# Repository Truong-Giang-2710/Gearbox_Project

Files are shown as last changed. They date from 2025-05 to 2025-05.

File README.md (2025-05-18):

📘 Mechanical Transmission System Design – Gearbox Project

🧑‍💻 Introduction
This is a personal project I undertook to strengthen my understanding and skills in the subject of Machine Elements / Mechanical Power Transmission System Design. The project focuses on the design and calculation of a complete mechanical transmission system including gears, shafts, bearings, keys, and the gearbox housing — commonly used in industrial machinery.
All calculations were performed manually, following mechanical engineering standards, design formulas, and technical tables learned throughout the course.

📚 Contents of the Work

I. Power Calculation & Transmission Characteristics
   Analyze working conditions and technical requirements
   Calculate power, torque, and load characteristics
   
II. Motor Selection & Transmission Ratio Distribution
   Select a suitable motor
   Determine the total transmission ratio and allocate it across the stages
   
III. Gear Train Design
   Select gear type: helical cylindrical gears
   Calculate key gear parameters: module, number of teeth, pitch, etc.
   Strength verification: contact stress and bending stress
   
IV. Shaft Design
   Define shaft layout and dimensions
   Calculate bending and torsional moments
   Stress analysis and deformation checks
   Key and spline design
   
V. Bearing Selection
   Choose bearing types based on load and speed
   Calculate bearing life and verify loading capacity
   
VI. Gearbox Housing Design
   Analyze the structure and function of the housing
   Design inspection holes, oil filling/draining holes
   Select bolts, locking rings, sealing elements, and auxiliary parts

🛠️ Tools & Methodologies Used
   Manual calculations based on Vietnamese/ISO mechanical standards
   Data from textbooks 
   Drafting in AutoCAD (optional)

🎯 Project Goals
   Mechanical design and calculation skills
   Develop a deep understanding of how individual machine elements work together in a transmission system
   Serve as a foundation for larger design projects or practical manufacturing applications

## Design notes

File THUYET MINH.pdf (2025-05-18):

### TRƯỜNG ĐẠI HỌC SƯ PHẠM KĨ THUẬT TPHCM

KHOA CƠ KHÍ CHẾ TẠO MÁY

BỘ MÔN CƠ SỞ THIẾT KẾ MÁY

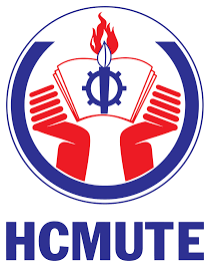
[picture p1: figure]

ĐỒ ÁN TRUYỀN ĐỘNG CƠ KHÍ (MMH: PRMD310523)

THUYẾT MINH TÍNH TOÁN THIẾT KẾ

GVHD : Nguyễn Lê Đăng Hải

GVPB : Nguyễn Văn Đoàn

SVTH : Tống Bạch Trường Giang

MSSV : 21146220
NHÓM: 02

TPHCM , Tháng 12 Năm 2023

Trường ĐHSPKT TP.HCM Khoa: Cơ khí Chế tạo máy Bộ môn: Cơ sở Thiết kế máy | ĐỒ ÁN THIẾT KẾ MÁY, MMH: : PRMD310523 THIẾT KẾ HỆ THỐNG XÍCH TẢI Đề số: 05 -- Phương án: 03
SVTH: Tống Bạch Trường Giang GVHD: Nguyễn Lê Đăng Hải Ngày nhận đề: 28/08/2023 | MSSV: 21146220 Chữ ký: Ngày bảo vệ: 05/01/2024

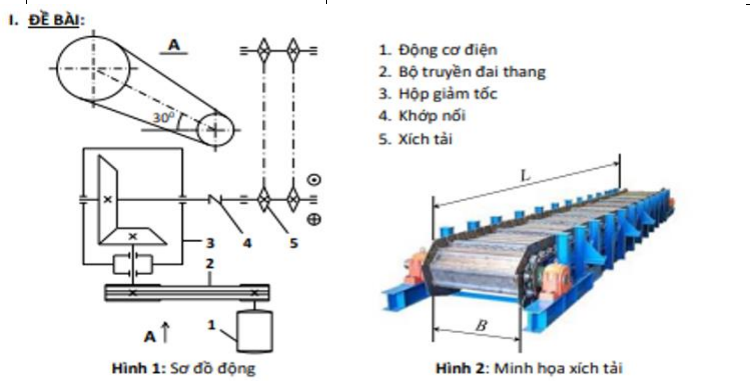
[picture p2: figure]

Điều kiện làm việc:
- Tải trọng không đổi, quay một chiều
- Thời gian làm việc 5 năm (300 ngày/năm, 2 ca/ngày, 6 giờ/ca) - Sai số tỉ
số truyền hệ thống |Δu⁄u| ≤ 5% Số liệu cho trước:
STT | Tên gọi | Giá trị
1 | Bước xích tải p (mm) | 100
2 | Số răng đĩa xích dẫn Z (răng) | 9
3 | Chiều rộng xích tải B (m) | 0,8
4 | Chiều dài xích tải L (m) | 12
5 | Trọng lượng vật đúc G (kG) | 120
6 | Vận tốc xích tải V (m/s) | 0.75
7 | Trọng lượng 1m dài xích tải q (kG/m) | 160

### MỤC LỤC

I. Tính toán công suất , tốc độ trục công tác

### 1.1 Tính toán công suất và tốc độ quay

Tốc độ quay trục công tác:

nlv =

6.10⁴
.V
Z.p

=

6.10⁴
.0,75
9.100

= 50 (v/p)

- Công suất trên trục công tác
Plv = 0,024.q.V.L + 0.00033.Q.L+0.006.Q.B = 3,58 (kW)

Thông số đầu ra :

- Công suất làm việc trên trục công tác : Plv = 3,58 (kW)
- Số vòng quay trên trục công tác : nlv = 50 (v/p)

II. Chọn động cơ và phân phối tỉ số truyền

### 2.1 Thông số đầu vào :

- Công suất cần thiết cần cung cấp: Plv = 3,58 kW
- Số vòng quay trục công tác : nlv = 50 (v/p)

### 2.2 Chọn động cơ :

- Công suất cần thiết trục động cơ : Pctdc=

Plv
η

=

3,58
0,9

= 3.96 kW

- Trong đó :
η = nx × nbrc × nkn × nol

3 = 1× 0,97 × 0.96 × 0,99³ = 0,9 nđ = 0,96 : Hiệu suất bộ truyền đai thang nbrc = 0,97 : Hiệu suất bộ truyền bánh răng côn . nkn = 1 : Hiệu suất khớp nối
nol = 0,99 : Hiệu suất một cặp ổ lăn
η : Hiệu suất truyền toàn hệ thống

+ Chọn sơ bộ tỉ số truyền => Chọn usb = 12

=> Số vòng quay sơ bộ : nsb = usb × nlv = 600 (v/p)
- Chọn động cơ : M2QA160M8A
- Tra bảng ABB với 380V/50Hz và điều kiện : {

Pct ≤ Pđc
nsb ~ nđc

Tmm
T

≤ Kqt ≤

Tk

Tdn

### 2.3 Phân phối tỉ số truyền :

- Tỉ số truyền thực của hệ thống : ut =

nđc

nlv

=

715
50

= 14,3

- Tỉ số truyền truyền động đai : uđ =

ut

ubrc

=

14,3
3,15

= 4,54

- Sai số tỉ số truyền hệ thống : ∆usb =

nđc – nsb

nsb

× 100% = 0.19%

- Sai lệch tỉ số truyền hệ thống :

n3 =

nđc
ut

=

715
14,3

= 50 (

v
p

)

∆uht =

n3 – nlv

nlv

=

50−50
50

∗ 100% = 0%

### 2.4 Bảng thông số kĩ thuật

- Công suất cần thiết trục công tác : Pct =

Plv

nol

=

3,82
0,99

= 3,62 (kW)

- Công suất cần thiết trên trục II : P2 =

Pct

nkn× nol

=

3,62
1×0,99

= 3,65 (kW)

- Công suất cần thiết trên trục I : P1 =

P2

nol × nbrc

=

3,65
0,99×0,97

= 3,96 (kW)

- Công suất cần thiết trục động cơ : Pđc =

P1
nđ

=

3,81
0,96

= 6,57 (kW)

- Số vòng quay trục I : n1 =

nđc
uđ

=

715
4,54

= 157,5 (

vòng
phút)
- Số vòng quay trục II : n2 =

n1
3,15

=

157,5
3,15

= 50 (

vòng
phút)
- Số vòng quay trục công tác : nct =

n2
1

=

50
1

= 50 (

vòng
phút)
- Momen xoắn trục động cơ : Tm =

9,55 ×10⁶×3,96

715

= 52953 N. mm

- Momen xoắn trục I | : T1 =

9,55 ×10⁶×3,81

157,5

= 230774 N. mm

- Momen xoắn trục II | : T2 =

9,55 ×10⁶×3,65

50

= 698081 N. mm

- Momen xoắn trục công tác : Tct =

9,55 ×10⁶×3,62

50

= 691100 N. mm

Động cơ | M2QA_160M8A
Công suất (kW) | 4
Số vòng quay (v/p) | 715
Hệ số quá tải ( Tk ) Tdn | 2,1
Khối lượng (kg) | 120
Đường kính trục động cơ | 42

Trục Thông số | Động cơ | Trục I | Trục II | Trục công tác (trục làm việc)
Công suất P, kW | 3,96 | 3,81 | 3,65 | 3,62
Tỉ số truyền u | 4,54 | 3,15 | 1
Số vòng quay n, vg/ph | 715 | 157,5 | 50 | 50
Mômen xoắn T, N,mm | 52953 | 230774 | 698081 | 691100

III. Tính toán bộ truyền đai

### 3.1 Thông số đầu vào :

- Công suất trên trục dẫn : Pct = 3,96 kW
- Số vòng quay trên trục dẫn: ndc = 715 (

vòng
phút)
- Tỉ số truyền bộ truyền đai: uđ = 4,54
- Đường kính bánh đai nhỏ: d1 =160 (mm)
- Đường kính bánh đai lớn: d2 =710 (mm)
- Tỉ số truyền thực tế : utt =

d2
d1.(1−ε)

=

710
160.(1−0.02)

= 4.53

- Kiểm tra sai lệch tỉ số truyền : ∆u =

ut – u
u

× 100% =

|4,53−4,54|
4,54

× 100% = 0.26% < 4%
- Xác định khoảng cách trục và chiều dài đai:

asơ bộ =

a
d

. d = 0,92.710 = 655,34

- Chiều dài đai tính toán :

l = 2a + π(d1+d2)
2

+

(d2−d1)^2
4a

= 2792,67 (mm)

=> Chọn chiều đai theo tiêu chuẩn : l = 2800 (mm)

- Tính lại chính xác khoảng cách trục :

a = 0,125.(2l-π(d1+d2)+√[2l − π(d1 + d2)] 2 − 8(d2 − d1)^2

= 659,36

- Tính góc ôm và kiểm tra điều kiện góc ôm :

α1 = 180 − 57. (

d2−d1
a

) = 180 -57. (

710−160
659,36

) = 132,45 (độ)

- Xác định số đai Z :

Z = P1⋅kđ
[P0
| ]⋅Cα.Cu.Cl
.Cz

= 2,49 (đai)

=> Chọn z = 3 (đai)

- Chiều rộng bánh đai: B = (z-1)t+2e = (3-1).19+2.12,5 = 63
- Đường kính ngoài của bánh đai : da = d1 + 2h0 = 160 + 2.4,2 = 168,4
- Lực căng ban đầu F0 = 274,23 ( N)
- Lực tác dụng lên trục: = 2F0zsin(α1/2) = 1505,75 (N)

### 3.2 Bảng thông số kĩ thuật bộ truyền đai :

Thông số | Kí hiệu | Gía trị | Đơn vị
Công suất trục dẫn | P | 3,58 | Kw
Tốc độ quay trục dẫn | n | 715 | v/p
Tỉ số truyền thực tế | ut | 4,53
Loại đai | Đai hình thang thường
Đường kính bánh đai nhỏ | d1 | 160 | mm
Đường kính bánh đai lớn | d2 | 710 | mm
Chiều dài đai | l | 2800 | mm
Khoảng cách trục | a | 659,36 | mm
Góc ôm | α1 | 132,45 | độ
Lực căng ban đầu | F0 | 274,23 | mm
Lực tác dụng lên trục | Fr | 1505,75 | N
Số đai | z | 4 | đai

IV. Tính toán thiết kế bộ truyền bánh răng

### 4.1 Thông số đầu vào :

- Công suất trên trục I : P1 = 3,81 N
- Tốc độ quay trên trục I : n1 = 157,5 (

v
p

)

- Tỉ số truyền bánh răng côn : ubrc = 3,15
- Thời gian làm việc : LH = 18000 (giờ)
- Momen xoắn trên trục I : T1 = 230774 N.mm

### 4.2 Tính toán bộ truyền bánh răng côn 4.2.1 Bảng thông tin vật liệu chế tạo bánh răng :

| Vật liệu | Nhiệt luyện | Độ cứng HB | Giới hạn bền σb (MPa) | Giới hạn cứng σch (MPa) | [σH] MPa | [σH]max MPa | [σF]max MPa
Bánh răng dẫn | C45 | Tôi cải thiện | 243 | 850 | 580 | 505,45 | 1624 | 464
Bánh răng bị dẫn | C45 | Tôi cải thiện | 228 | 750 | 450 | 478,18 | 1260 | 360

### 4.2.2 Xác định ứng suất cho phép 4.2.2.1 Ứng suất tiếp xúc cho phép :

[σH1] = σHlim1×KHL1
SH

=

570×1
1,1

= 505,45 MPa

[σH2] = σHlim2×KHL2
SH

=

540×1
1,1

= 478,18 MPa

Trong đó:
- σHlim1= 2×HB1 + 70 = 556 MPa : Ứng suất tiếp cho phép
- σHlim2= 2×HB2 + 70 = 526 MPa : Ứng suất tiếp cho phép
- [σH] = min {[σH1] , [σH2]} = 478,18 MPa
- SH = 1,1 : hệ số an toàn khi tính về tiếp xúc
- KFL = 1
- NHO = 30 × HB: Số chu kì thay đổi ứng suất khí tiếp xúc .
- NHE = 60 × c × n × LH = 170100000

- LH = 18000 : thời gian làm việc (giờ)
- Do NHE1,2 > NHO1,2 → NHE1,2 = NHO1,2
4.2.2.2 Ứng suất uốn cho phép :

[σF1] = σFlim1×KFC×KFL

| SF = 450×1×1
| 1,75 = 257,1 MPa

[σF2] = σFlim2×KFC×KFL

| SF = 423×1×1
| 1,75 = 241,7 MPa

Trong đó:
- σFlim1= 1,8×HB1 = 437 MPa : Ứng suất uốn cho phép
- σFlim2= 1,8×HB2 = 410 MPa : Ứng suất uốn cho phép
- SF = 1,75 : hệ số an toàn khi tính về uốn
- KFL = (
| NFO NFE
)
| 1 mF = 1 ∶ hệ số tuổi thọ xét đến ảnh hưởng tải trọng
- KFC = 1 : hệ số xét đến ảnh hưởng đặt tải
- NHO = 30 × HB ∶ Số chu kì thay đổi ứng suất khí tiếp xúc .
- NFO = 4 × 10⁶
| ∶ Số chu kì thay đổi ứng suất cơ sở khi uốn
- NHE = 60 × c × n × LH = 170100000
- c = 1 ∶ số lần tiếp xúc / vòng quay
- LH = 18000 : thời gian làm việc (giờ)
- Do NFE1,2 > NFO1,2 → NFE1,2 = NFO1,2
4.2.2.3 Ứng suất tiếp cho phép khi quá tải. [σH1]max = 2,8 × σch1 = 2,8 × 580 = 1624 MPa [σH2]max = 2,8 × σch2 = 2,8 × 450 = 1260 MPa 4.2.2.4 Ứng suất uốn cho phép khi quá tải. [σF1]max = 0,8 × σch1 = 0,8 × 580 = 464 MPa [σH2]max = 0,8 × σch2 = 0,8 × 450 = 360 MPa

### 4.2.3 Xác định sơ bộ chiều dài côn ngoài

Re = KR × √u

2 + 1 × √
(T1×KHβ)
(1−Kbe)×Kbe×u×[σH]

2 = 203,47 (mm)

Trong đó :
- KR = 50 : hệ số phụ thuộc vào vật liệu bánh răng và loại răng
- KHβ = 1,09 : hệ số kể đến ảnh hưởng đến sự phân bố không đều tải trọng trên chiều rộng vành răng
- Kbe =

b
Re

= 0,25 vì u > 3

- Đường kính chia ngoài :
de1 = 2 ×

Re
√1+u² = 2 ×

203,47
√1+3,15²

= 123,13 (mm)

- Xác định số răng bánh dẫn :
z1 = 1,6× z1p = 1,6 × 19,93 = 31,88 → Chọn z1 = 32 (răng)
- Đường kính trung bình : dm1 = (1 − 0,5 × Kbe) × de1 = 107,74 (mm)
- Modun trung bình : mtm =

dm1
z1

=

107,74
32

= 3,37

- Modun vòng ngoài:
mte =

mtm
1−0,5.Kbe

=

3,37
1−0,5.0,25

= 3,85 , chọn mte = 4

Tính lại mtm = mte ×(1 − 0,5 × Kbe) = 3,5
- Tính lại số răng z1 =

dm1

mtm

=

107,74
3,5

= 30,78 −→ chọn z1 = 31 răng

➔ z2 = u× z1 = 3,15× 31 = 97,65 → Chọn z2 = 98 răng
- Tính lại tỉ số truyền thực tế: utt =

z2
z1

=

98
31

= 3,16

- Sai lệch tỉ số truyền :

∆u =

utt – ubrc

ubrc

× 100% =

|3,16−3,15|
3,15

× 100% = 0,36% < 4%

- Sai lệch tỉ số truyền hệ thống:

∆u =

n3– nlv

nlv

× 100% =

|49,94−50|
50

× 100% = 0,1% < 5%

Trong đó:
- n3 =

nđc

ubrtt×ut

=

715
3,16×4,53

= 49,95 (

v
p

)

- Xác định góc ôm chia theo công thức: δ1 = arctg (

z1
z2

) = 17,55°

δ2 = 90° − 17,55° = 72,45°

- Đường kính trung bình và chiều dài côn ngoài: dm1 = z1 × mtm = 31×3,5 = 108,5 mm
Re = 0,5 × mte × √z1
2 + z2

2 = 205,57 mm
- Độ rộng vành răng b = Kbe × Re = 51,39 mm

### 4.2.4 Kiểm nghiệm răng về độ bề tiếp xúc

σH = zM × zH × zξ√
2×T1×KH×√u²+1
0,85×b×u×dm1

2
= 274× 1,76 × 0,87 × √
2×87753×1,24×√3,17²+1
0,85×36,17×3,17×76,125²

= 474 ,82 MPa ≤ [σH]

Trong đó:
- zM = 274 : hệ số kể đến cơ tính vật liệu của các bánh răng khớp
- zH = 1,76 : hệ số kể đến hình mặt bề mặt tiếp xúc
- zξ = √
4−ξα
3

= √
4−1,73
3

= 0,87 hệ số kể đến sự trùng khớp của răng

- ξα = [1,88 − 3,2 × (

1
z1

+

1
z2

)] × cos (0) = 1,73

- KH = kHβ × kH∝ × kHv = 1,15: hệ số tải trọng khi tính về tiếp xúc
- kHβ = 1,09
- kH∝ = 1 : hệ số kể đến sự phân bố không đều tải trọng cho các đôi răng khi đồng thời ăn khớp.
- kHv = 1 +

vH×b×dm1
2×T1×kHβ×kH∝

= 1,05 : hệ số kể đến tải trọng xuất hiện trong vùng

ăn khớp
- vH = δH × go × v × √
dm1×(u+1)
u
= 0,006× 56 × 0,89 × √
108,5×(3,15+1)
3,15

= 4,69 ≤ VHmax = 700

- δH = 0,006 : ảnh hưởng sai số ăn khớp
- go = 73: ảnh hưởng sai lệch các bước bánh răng 1 và 2
- v = dm1 × π ×

n
60000

= 0.89

- VHmax = 380 : khả năng chịu tải trọng lớn của bánh răng
- Kiểm nghiệm độ bền: σH ≤ [σH]
[σH] − σH
[σH]

× 100% =

434,99 − 478,18
478,18 × 100% = 9% < 10%

### 4.2.5 Kiểm nghiệm răng về độ bền uốn

σF1 =

2×T1×KF×Yξ×Yβ×YF1
0,85×b×mtm×dm1

=

2×230774×1,33×0,57×1×3,79
0,85×51,39×3,5×108,5

= 80,17 MPa

σF2 =

σF1×YF2

YF1

=

80,17×3,6
3,79

= 76,17 MPa

Trong đó:
- Yξ =

1
ξα

= 0,57 : hệ số kể đến sự trùng khớp của răng

- Yβ = 1 −

β

°

140

= 1 : hệ số kể đến độ nghiên của răng

- {

YF1 = 3,82
YF2 = 3,6

: hệ số dạng răng của bánh răng 1 và 2

- zv1 =

z1
[cos (β°)]

3 = 31

- zv2 =

z2
[cos (β°)]

3 = 98

- KF = kFβ × kF∝ × kFv = 1,33 : hệ số tải trọng khi tính về uốn
- kFβ = 1,175 tra bảng 6,21 : hệ số kể đến sự phân bố không đều tải trọng trên chiều rộng vành răng.
- kF∝ = 1 : hệ số kể đến sự phân bố không đều tải trọng cho các đôi răng khi đồng thời ăn khớp.
- kFv = 1 +

vF×b×dm1
2×T1×kFβ×kF∝

= 1 +

12,49×51,39×108,5
2×230774×1,175×1

= 1,13 : hệ số kể đến tải trọng

xuất hiện trong vùng ăn khớp
- vF = δF × go × v × √
dm1×(u+1)
u
= 0,016× 73 × 0,89 × √
108,5×(3,15+1)
3,15

= 12,49

- δF = 0,016 : ảnh hưởng sai số ăn khớp
- go = 73: ảnh hưởng sai lệch các bước bánh răng 1 và 2

### 4.2.6 Kiểm nghiệm răng về quá tải

- Kiểm tra ứng suất tiếp cực đại cho phép
σHmax = σH × √Kqt = 434,99× √1 = 434,99 ≤ [σHmax] -Kiểm nghiệm ứng suất uốn cực đại cho phép:
σF1max = σF1 × Kqt = 80,17 × 1 = 80,17≤ [σF1max] σF2max = σF2 × Kqt = 76,17 × 1 = 76,17≤ [σF2max]

### 4.2.7 Lực tác dụng khi ăn khớp:

- Lực vòng : Ft1 = 2 ×

T1

dm1

= 2 ×

230774
108,5

= 4253,91 = Ft2

- Lực hướng tâm :
Fr1 = Ft1 × tg(∝) × cosδ1 = Fa2
= 4253,91 × tg(20°) × cos(17,55°) = 1476,2 N
- Lực dọc trục ∶
Fa1 = Ft1 × tg(∝) × sinδ1 = Fr2
= 4253,91 × tg(20°) × sin(17,55°) = 466,96 N

### 4.2.8 Các thông số khác :

- Đường kính chia ngoài:
{

de1 = mte × z1 = 4 × 31 = 124 mm de2 = mte × z2 = 4 × 98 = 392 mm
- Chiều cao đầu răng ngoài :
{

hae1 = hte + x × cos (0) = 5,212 mm hae2 = 2 × hte × mte − hae1 = 2,788 mm
- Chiều cao răng ngoài
he = 2 × hte × mte + c = 8,8 mm , hte = 1
- Chiều cao chân răng ngoài :
{

hfe1 = (he − hae1) = 3,588 mm
hfe2 = (he − hae2) = 6,012 mm
- Đường kính đỉnh côn ngoài: {

da1 = de1 + 2 × hae1 × cos (δ1) = 133,94 mm da2 = de2 + 2 × hae2 × cos (δ2) = 393,68 mm

### 4.3 Bảng thông số kĩ thuật bộ truyền bánh răng côn:

Thông số | Ký hiệu | Giá trị | Đơn vị
Tỉ số truyền | ubr | 3.15
Chiều dài côn ngoài | Re | 205,57 | mm
Mô đun vòng ngoài | mte | 4 | mm
Số răng của bánh răng dẫn | z1 | 31 | răng
Số răng của bánh răng bị dẫn | z2 | 98 | răng
Đường kính chia ngoài của bánh dẫn | de1 | 124 | mm
Đường kính chia ngoài của bánh bị dẫn | de2 | 392 | mm
Góc côn chia của bánh dẫn | δ1 | 17.55 | độ
Góc côn chia của bánh bị dẫn | δ2 | 72.45 | độ
Đường kính đỉnh răng ngoài của bánh dẫn | dae1 | 133.94 | mm
Đường kính đỉnh răng ngoài của bánh bị dẫn | dae2 | 393.68 | mm
Đường kính trung bình của bánh dẫn | dm1 | 108.5 | mm
Đường kính trung bình của bánh bị dẫn | dm2 | 343 | mm
Chiều cao răng ngoài | he | 8.8 | mm
Chiều cao đầu răng ngoài của bánh dẫn | hae1 | 5.212 | mm
Chiều cao đầu răng ngoài của bánh bị dẫn | hae2 | 2.788 | mm
Chiều cao chân răng ngoài của bánh dẫn | hfe1 | 3,588 | mm
Chiều cao chân răng ngoài của bánh bị dẫn | hfe2 | 6.012 | mm
Lực vòng | Ft1 = Ft2 | 4253 | N

Lực hướng tâm | Fr1, Fr2 | 1476;466 | N
Lực dọc trục | Fa1, Fa2 | 466;1476 | N
V. Tính toán thiết kế trục

### 5.1 Thông số đầu vào :

- Momen xoắn cần truyền: T = 698081 (N.mm)
- Đặc trưng tải trọng : máy công tác thùng trộn

### 5.2 Chọn nối trục :

- Momen xoắn tính toán: Tt = k× T = 1,5 × 698081 = 1047121 N.mm Trong đó k = 1,5 : hệ số an toàn làm việc
- Chọn đường kính sơ bộ tại vị trí lắp trục
d ≥ √
1047121
0,2×22

3
= 61,97 (mm)

➔ Chọn d = 63 mm
- Kích thước cơ bản của nối trục vòng đàn hồi.
T (N.m) | d | D | dm | L | l | d1 | D0 | Z | nmax | B | B1
2000 | 63 | 260 | 120 | 175 | 140 | 110 | 200 | 8 | 2300 | 8 | 70
T (N.m) | l1 | D3 | l2 | dc | d1 | D2 | l | l1 | l2 | l3 | h
2000 | 48 | 48 | 48 | 24 | M16 | 32 | 95 | 52 | 24 | 44 | 2

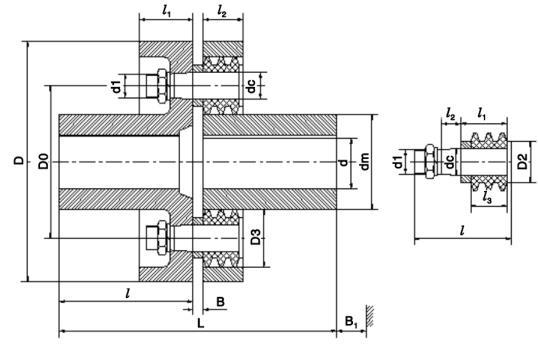
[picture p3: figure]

- Điều kiện sức bền dập vòng đàn hồi:

σd =

2×k×T
Z×D0×dc×l3

=

2×1,5×698081
8×200×24×44

= 1,24 MPa ≤ (2 ÷ 4)MPa

- Điều kiện bền của chốt :

σu =

k×T×l0
0,1×D0×dc

3×Z

=

1,5×698081×72
0,1×200×24³×8

= 34,09 MPa ≤ [σu]

l0 = l1 +

l2
2

= 48 +

48
2

= 72 (mm)

- Lực nối trục : Frnt = 0,2 × 2 ×

698081
200

= 1745,2 N.

### 5.3 Tính toán thiết kế trục :

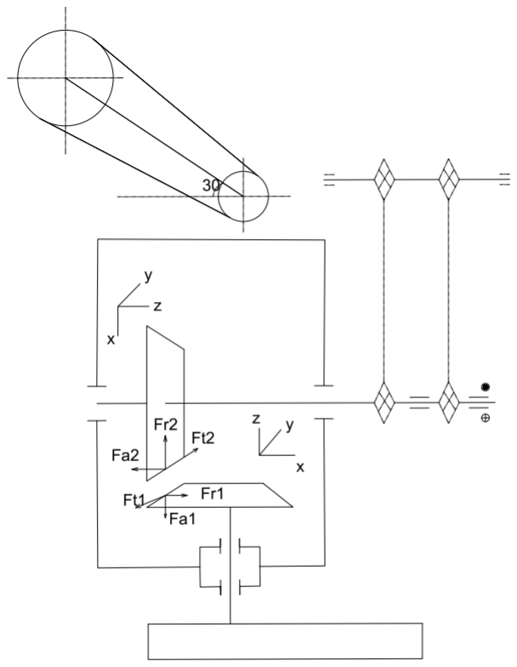
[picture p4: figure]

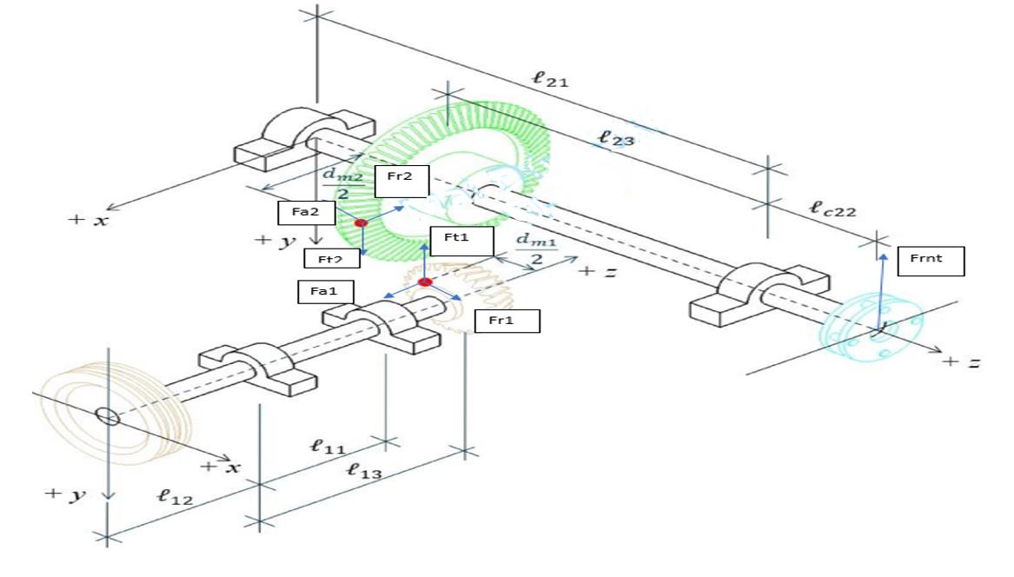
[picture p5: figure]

### 5.3.1 Tính toán tải tác dụng lên trục:

- Lực vòng : Ft1 = Ft2 = 2 ×

T1

dm1

= 2 ×

230774
108,5

= 4253,92 N
- Lực hướng tâm : Fr1 = Fa2 = Ft1 × tg(∝) × cosδ1 = 4253,92 × tg(20°) × cos(17,55°) = 1476,2 N
- Lực dọc trục : Fa1 = Fr2 = Ft1 × tg(∝) × sinδ1 = 2305,5 × tg(20°) × sin(17,49°) = 252,2 N

### 5.3.2 Tính toán sơ bộ đường kính trục

d1 ≥ √
T1
0,2×[τ1]

3

= √
230774
0,2×18

3
= 40 mm => Chọn d1 = 45 mm

d2 ≥ √
T2
0,2×[τ2]

3

= √
265488
0,2×22

3
= 54,14 mm => Chọn d2 =55 mm

Trong đó:
- {

[τ1] = 18
[τ2] = 22

∶ Ứng suất trượt cho phép.

### 5.3.3 Khoảng cách giữa các gối đỡ

- Chiều dài mayo mấy răng côn trục I :
lm13 = (1,2 ÷ 1,4) × d1 = 1,3.45 = 58,5 mm
- Chiều dài mayo bánh đai
lm12 = (1,4 ÷ 2,5) × d1 = 1,5.45 = 67,5 mm
- Chiều dài mayo mấy răng côn trục II :
lm23 = (1,2 ÷ 1,4) × d2 = 1,3.55 = 71,5mm
- Chiều dài mayo khớp nối trục II:
lm22 = (1,2 ÷ 1,5) × d2 = 1,5.55 = 82,5mm Chọn sơ bộ bề rộng ổ lăn:
d1 = 35 mm → chọn b01 = 21 mm
d2 = 40 mm → chọn b02 = 23 mm

### 5.3.4 Chọn trị số các khoảng cách

- k1 = 15 : Khoảng cách từ mặt mút chi tiết quay đến thành trong của hộp
- k2 = 10 : Khoảng cách từ mặt mút ổ đến thành trong của hộp
- k3 = 20 : Khoảng cách từ mặt mút của chi tiết quay đến nắp ổ
- hn = 20 : Chiều cao nắp ổ và đầu bu lông .

### 5.3.5 Khoảng cách trục I:

lc12 = 0,5× (lm12 + b01)+k3+hn = 0,5× (67,5 + 25) + 20 + 20 = 86,25 mm l12 = lc12 = 86,25 mm
l11 = (2,5 ÷ 3) × d1= 135 mm
l13 = l11+k1+k2+lm13+0,5×(b01- b13 × cos (δ1)) = 206,5 mm

### 5.3.6 Khoảng cách trục II:

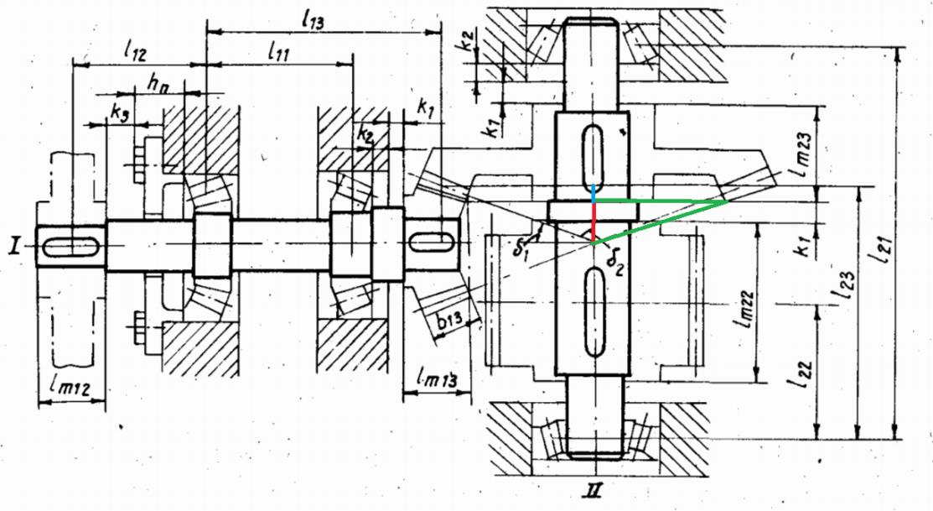
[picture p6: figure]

- Góc tạo bởi đỉnh bánh răng lớn và đường ăn khớp : θ = arctg (

hae2
Re

) = arctg (

2,788
205,57) = 0,78°
- Góc tạo bởi đỉnh bánh răng lớn và tâm trục I:
γ = δ1 − θ = 17,55 – 0,78= 16,77°
- Bề rộng đỉnh bánh răng lớn :
b1 = b × cos(θ) = 51,39 × cos(0,78) = 51,385 mm
- Khoảng cách đoạn màu đỏ :
y = cos(16,77) ×51,385=49,2 mm
- Khoảng cách từ

b
2

đến đường tâm trục I (đỏ + xanh)

s = √(Re −
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
× cos(δ1

))

2
= 54,01 mm
- Khoảng cách trục II :
lc22 = 0,5× (lm22 + b02)+k3+hn = 0,5×(82,5+29)+20+20 = 95,75 mm l21= 2× (

b02
2

+ k1 + k2 + lm23 + y) = 320,4 mm

l23 = (

l21
2

+ s) = 214,44 mm

l22 = lc22 = 95,75 mm

### 5.4 Vẽ biểu đồ momen nội lực :

### 5.4.1 Tính phản lực trên trục I :

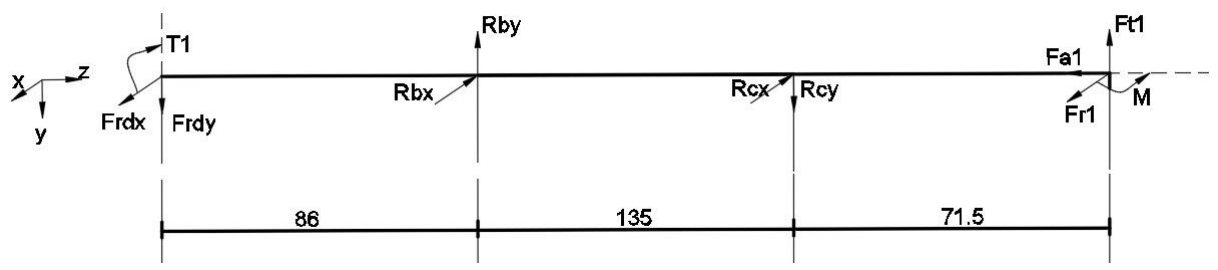
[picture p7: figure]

Xét Oyz :

MB = 0 Frdy.l12+Ft1.l13-Rcy.l11=0

- 752,88.86,25+4253,91.206,5- Rcy.135 = 0
- Rcy = 6987,92 (N)
Fy = 0 | Frdy +Rcy -Ft1 – Rby = 0
| 752,88 + 6987,92-4253,92 – Rby = 0
| Rby = 3486,88 (N)

Xét Oxz : -Frdx.l12+Fr1.l13-M1 – Rcx.l11 = 0

| -1304,02.86,25+1476,2.206,5-25332,69- Rcx .135= 0
| Rcx = 1237,27 (N)
Fx = 0 | Frdx -Rcx +Fr1 – Rbx = 0
| 1304,02 - 1237,27+1476,2 – Rbx = 0
| Rbx = 1542,95 (N)

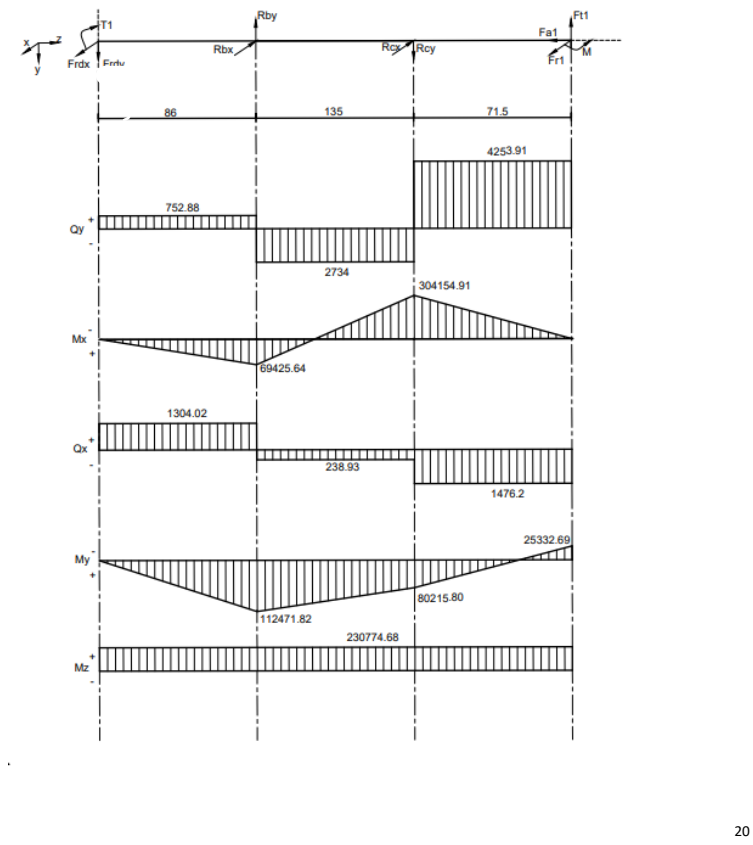
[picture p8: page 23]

### 5.4.2 Phản lực trên trục II :

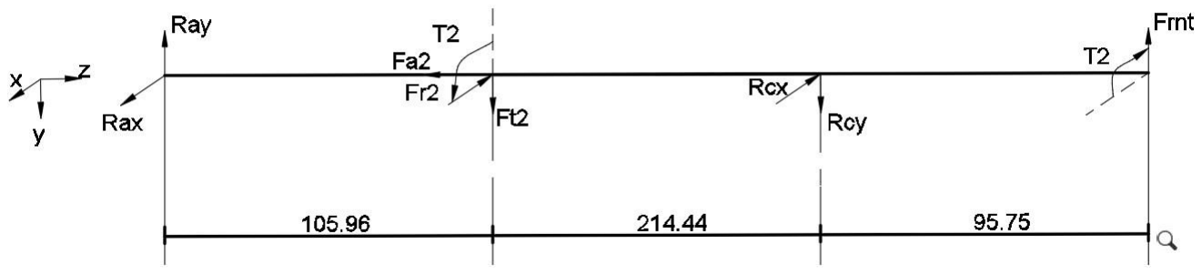
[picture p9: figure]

MC = 0 Ft2.l23+Frnt.l22-Ray.l21=0

- 4253,91.214,44+1745,2.95,75- Ray.320,4 = 0
- Ray = 3368,64 (N)
Fy = 0 | Frnt +Ray -Ft2 – Rcy = 0
| 1745,2 + 3368,64-4253,92 – Rcy = 0
| Rcy = 859,93 (N)

MC = 0 Fr2.l23+ M – Rax.l21 = 0

466,96.214,44 +253168,76- Rax .320,4= 0

- Rax = 1102,7 (N)
Fx = 0 | Rax -Fr2 – Rcx = 0
| 1102,69 -466,96 – Rcx = 0
| Rcx = 635,73 (N)

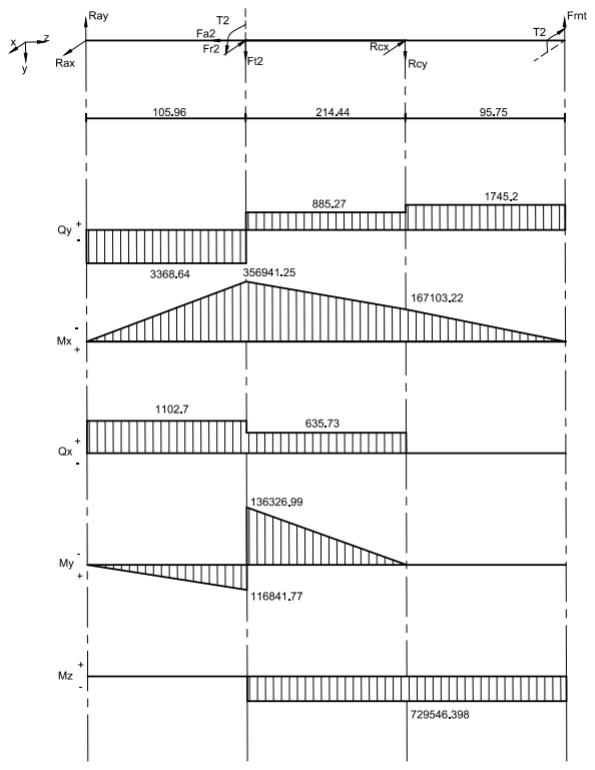
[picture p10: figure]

### 5.5 Tính đư

ờng kính tr
ục t

ại các ti

ết di
ện nguy hi

ểm :

- Trục I : Đư
ờng kính tr

ục đ
ộng cơ D = 42 mm
- Tra b
ảng 10.5 , t

ừ

d
1

= 45 mm
C

h
ọn

σ
1

= 55 MPa
•

T

ại ti

ết di
ện A

d
A

≥

√
MtdA

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
= 33,12 => Ch
ọn

d
A = 34 mm

•

T

ại ti

ết di
ện B

d
B

≥

√
MtdB

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
= 35,12 =>Ch
ọn

d
B = 45 mm

•

T

ại ti

ết di
ện C

d
C

≥

√
MtdC

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
= 40,77 =>Ch
ọn

d
C = 45 mm

•

T

ại ti

ết di
ện D

d
D

≥

√
MtdD

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
= 33,21 => Ch
ọn

d
D = 34 mm
- Trục II : • Tra bảng 10.5 , t ừ

d
1

= 55 mm

, ch
ọn

σ
1

= 55 MPa
•

T

ại ti

ết di
ện A

d
A

≥

√
MtdA

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
= 0 , Ch
ọn

d
A = 65 mm

•

T

ại ti

ết di
ện B

d
B

≥

√
MtdB

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
= 51,2 , Ch
ọn

d
B = 70 mm

•

T

ại ti

ết di
ện C

d
C

≥

√
MtdC

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
= 49,16 , Ch
ọn

d
C = 65 mm

•

T

ại ti

ết di
ện D

d
D

≥

√
MtdD

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
= 48,61 , Ch
ọn

d
D = 63 mm

### 5.6 Chọn và kiểm nghiệm then :

- Dựa vào đường kính trục chọn theo bảng sau:
| d(mm) | Kích thước tiết diện | Chiều sâu rãnh | Vị trí lắp
b | h | t1 | lt
Trục I | A | 34 | 10 | 8 | 5 | 57,38 | Bánh đai
| D | 34 | 10 | 8 | 5 | 49,73 | Bánh răng dẫn
Trục II | B | 70 | 20 | 12 | 7,5 | 60,78 | Bánh răng bị dẫn
| D | 63 | 18 | 11 | 7 | 70,13 | Khớp nối
- Tính chiều dài then:

Trục I: {

Tại A: ltA = (0,8 ÷ 0,9) × lm12 = 57,4 mm Tại D: ltD = (0,8 ÷ 0,9) × lm13 = 49,7 mm Trục II: {

Tại B: ltB = (0,8 ÷ 0,9) × lm23 = 60,8 mm Tại D: ltD = (0,8 ÷ 0,9) × lm22 = 70,1 mm
- Kiểm nghiệm then:
Trục I
Tại tiết diện A : {
σd =

2×T1
dA×ltA×(h−t1)

=

2×230774
34×57,4×(8−5)

= 78,87 ≤ [σd]

τC =

2×T1
dA×ltA×b

=

2×230774
34×57,4×10

= 23,66 ≤ [τc

]

Tại tiết diện D : {
σd =

2×T1
dD×ltD×(h−t1)

=

2×230774
34×49,7×(8−5)

= 91 ≤ [σd]

τC =

2×T1
dD×ltD×b

=

2×230774
34×49,7×10

= 27,3 ≤ [τc

]

Trục II:
Tại tiết diện B : {
σd =

2×T2
dB×ltB×(h−t1)

=

2×729546
70×60,8×(12−7,5)

= 76,22 ≤ [σd]

τC =

2×T2
dB×ltB×b

=

2×729546
70×60,8×20

= 17,15 ≤ [τc

]

Tại tiết diện D : {
σd =

2×T2
dD×ltD×(h−t1)

=

2×729546
63×70,1×(11−7)

= 82,57 ≤ [σd]

τC =

2×T2
dD×ltD×b

=

2×729546
63×70,1×18

= 17,78 ≤ [τc

]

### 5.7 Kiểm nghiệm về bền mỏi Trục :

σ−1 = 0,436 × σb = 0,436 × 850 = 370,6 MPa τ−1 = 0,58 × σ−1= 214,95 MPa
- Bảng 10.7 chọn ψσ = 0,1 , ψτ = 0,05 .
- Bảng 10.12 với σb = 850 → nội suy => {

kσ = 1,6575
kτ = 1,965
- Bảng 10.11 chọn {

kσ
ξσ

= 3,375

kτ
ξτ

= 2,425

- Kiểm nghiệm trục về độ bền mỏi tại các vị trí nguy hiểm
Trục | dA1 | dD1 | dB2 | dD2
d(mm) | 34 | 34 | 70 | 63
εσ | 0,85 | 0,85 | 0,76 | 0,81
ετ | 0,78 | 0,78 | 0,73 | 0,76

VI. Chọn ổ lăn

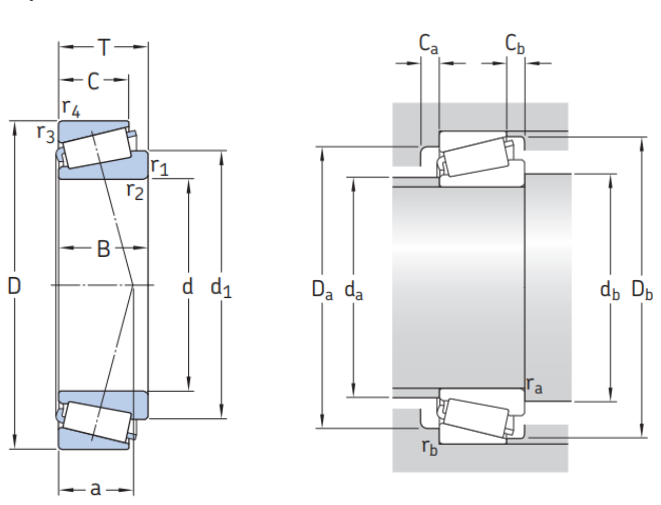
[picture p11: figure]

### 6.1 Trục I :

6.1.1 Thông số đầu vào :
- Đường kính tại B và C: dB = dC = 45 mm
- Momen xoắn trục I : T1= 230774 N.mm
- Tốc độ quay trục : n1= 715 v/p
6.1.2 Chọn loại ổ
- Chọn kích thước ổ:
Kí hiệu | d | D | B | Tải tỉnh Co (KN) | Tải động C (KN) | Khối lượng(Kg) | e
32008X/Q | 45 | 80 | 26 | 43 | 44,6 | 13,67 | 0,37

### 6.2 Trục II:

6.2.1 Thông số đầu vào :
- Đường kính tại B và D : dB = dC = 65 mm
- Momen xoắn trục II : T2= 729546 N.mm
- Tốc độ quay trục : n2= 50 v/p
6.2.2 Chọn loại ổ
- Chọn kích thước ổ:
Kí hiệu | d | D | B | Tải tỉnh Co (KN) | Tải động C (KN) | Khối lượng(Kg) | e
JM511946 | 65 | 110 | 28 | 183 | 123 | 1.05 | 0,88

PHẦN VII: THIẾT KẾ VỎ HỘP

Bảng thông số vỏ hộp:
Vật liệu đúc vỏ hộp: gang xám GX 15-32
Tên gọi | Thông số | Giá trị | Đơn vị
Chiều dày | Thân hộp | δ | 9 | mm
| Nắp hộp | δ1 | 8 | mm
Đường kính | Bulông nền | d1 | 16 | mm
| Bulông cạnh ổ | d2 | 12 | mm
| Bulông ghép bích nắp và thân | d3 | 10 | mm
| Vít ghép nắp ổ | d4 | 8 | mm
| Vít ghép nắp cửa thăm | d5 | 6 | mm
Mặt bích ghép nắp và thân | Chiều dày bích thân hộp | S3 | 16 | mm
| Chiều dày bích nắp hộp | S4 | 16 | mm
| Bề rộng bích nắp và thân | K3 | 37 | mm
Kích thước gối trục | Đường kính ngoài và tâm lỗ vít | D12 | 75 | mm
| | D13 | 90 | mm
| | D22 | 100 | mm
| | D23 | 125 | mm
| Bề rộng mặt ghép bulông cạnh ổ | K2 | 45 | mm
| Tâm lỗ bulông cạnh ổ | C1 | 45 | mm
| | C2 | 63 | mm
| Chiều dày | e | 8 | mm
| Chiều cao | h | < 58 | mm

Gân tăng cứng

Độ dốc | | 2 o
Mặt đế hộp | Chiều dày (không có phần lồi) | S1 | 24 | mm
| Bề rộng mặt đế hộp | K1 | 48 | mm
Khe hở giữa các chi tiết | Giữa bánh răng và thành trong hộp | ∆ | 10 | mm
| Giữa bánh răng lớn với đáy hộp | ∆1 | 24 | mm
| Giữa mặt bên các bánh răng với nhau | ∆ | 10 | mm
Số lượng bulông nền | | Z | 4

Một số chi tiết phụ :
- Bulông vòng:
- Chức năng: để nâng và vận chuyển hộp giảm tốc (khi gia công, khi lắp ghép,…) nên nắp và thân thường lắp bulông vòng hoặc vòng móc.
- Với Re = 144,69 mm
- khối lượng hộp giảm tốc bánh răng côn Q = 60 kg

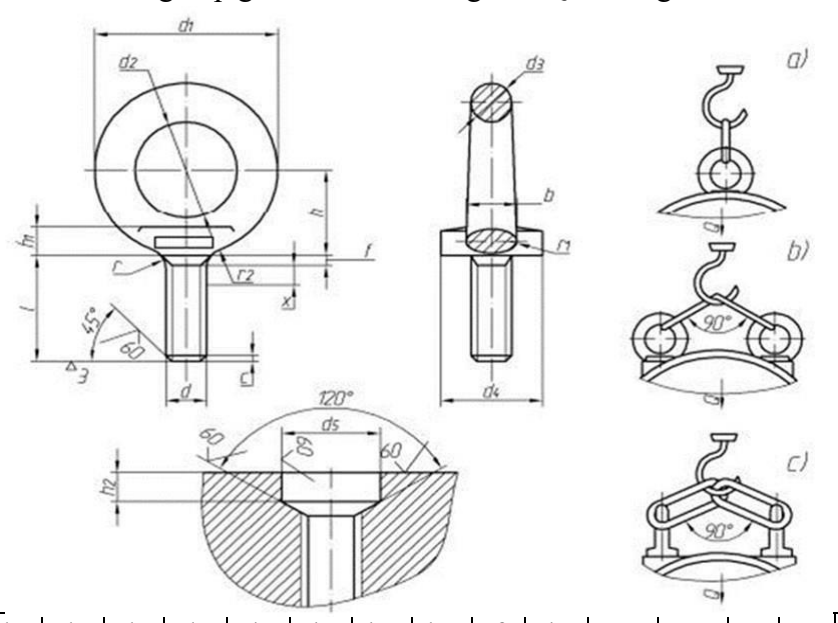
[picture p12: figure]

Ren d | d1 | d2 | d3 | d4 | d5 | h | h1 | h2 | f | b | c | x | r | r1 | r2 | l
M8 | 36 | 20 | 8 | 20 | 13 | 18 | 6 | 5 | 2 | 10 | 1.2 | 2.5 | - | 4 | 4 | 18
- Chốt định vị:
- Chức năng: khi xiết bulông không làm biến dạng vòng ngoài của ổ, do đó loại trừ được một trong nguyên nhân làm ổ chóng bị hỏng. Chọn chốt định vị: chốt định vị hình côn

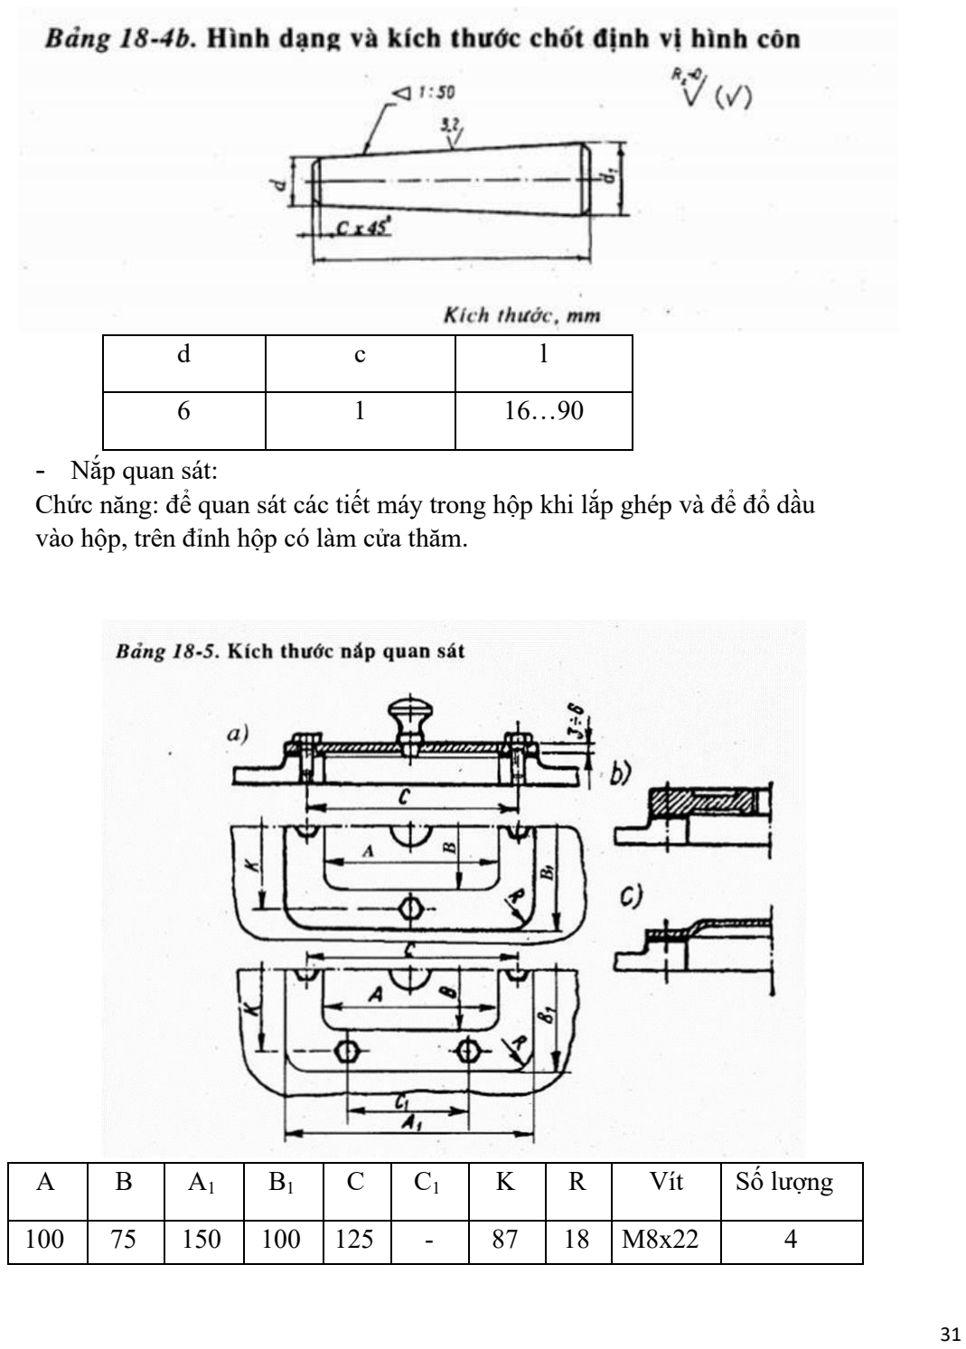
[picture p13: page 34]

d | c | l
6 | 1 | 16…90
- Nắp quan sát:
Chức năng: để quan sát các tiết máy trong hộp khi lắp ghép và để đổ dầu vào hộp, trên đỉnh hộp có làm cửa thăm.
A | B | A1 | B1 | C | C1 | K | R | Vít | Số lượng
100 | 75 | 150 | 100 | 125 | - | 87 | 18 | M8x22 | 4

- Nút thông hơi:
- Chức năng: khi làm việc nhiệt độ trong hộp tăng lên. Để giảm áp suất và điều hòa không khí bên trong và bên ngoài hộp, người ta dùng nút thông hơi.

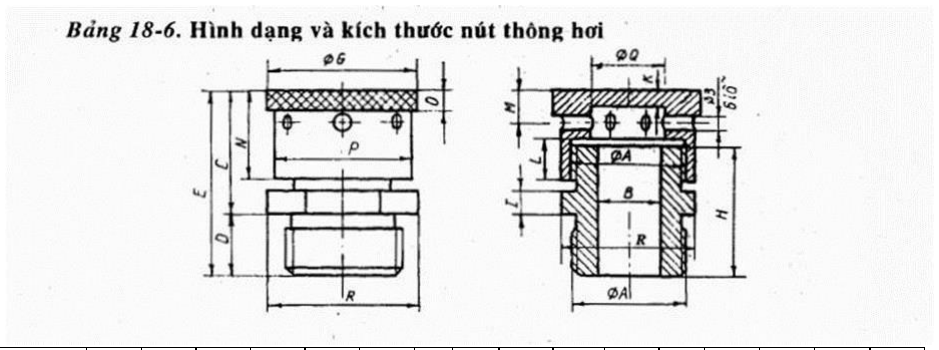
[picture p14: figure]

A | B | C | D | E | G | H | I | K | L | M | N | O | P | Q | R | S
M27X 2 | 1 5 | 3 0 | 1 5 | 4 5 | 3 6 | 3 2 | 6 | 4 | 1 0 | 8 | 2 2 | 6 | 3 2 | 1 8 | 3 6 | 3 2
- Nút tháo dầu:
- Chức năng: sau một thời gian làm việc, dầu bôi trơn chứa trong hộp bị bẩn (do bụi bặm và do hạt mài), hoặc bị biến chất, do đó cần phải thay dầu mới. Để tháo dầu cũ, ở đáy hộp có lỗ thảo dầu. Lúc làm việc lỗ được bịt kín bằng nút tháo dầu.

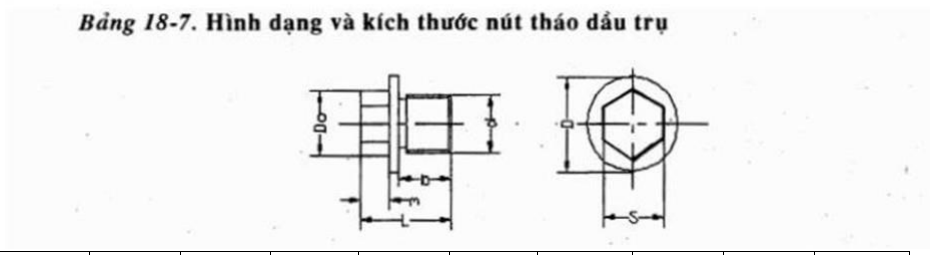
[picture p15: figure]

d | b | m | f | L | c | q | D | S | D0
M20x2 | 15 | 9 | 3 | 23 | 2 | 13.8 | 26 | 17 | 19.6
- Que thăm dầu:
- Chức năng: khi vận tốc bánh răng được ngâm trong dầu. Chiều cao mức dầu trong hộp được kiểm tra qua thiết bị chỉ dầu là que thăm dầu.

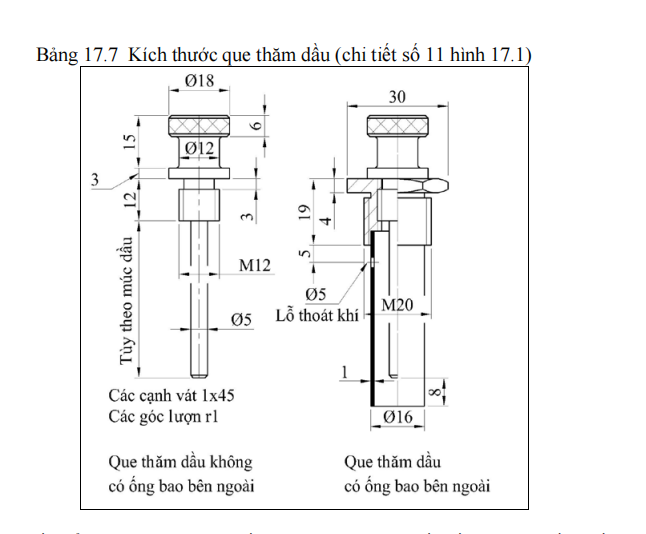
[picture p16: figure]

Tài liệu kham khảo:
PGS. TS. Trịnh Chất – TS. Lê Văn Uyển (1999), Tính toán thiết kế hệ dẫn động cơ khí tập 1, Nxb. Giáo dục Việt Nam, Tp. Hồ Chí Minh. PGS. TS. Trịnh Chất – TS. Lê Văn Uyển (1999), Tính toán thiết kế hệ dẫn động cơ khí tập 2, Nxb. Giáo dục Việt Nam, Tp. Hồ Chí Minh.

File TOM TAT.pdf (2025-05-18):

TRƯỜNG ĐẠI HỌC SƯ PHẠM KĨ THUẬT THÀNH PHỐ HỒ CHÍ MINH

KHOA CƠ KHÍ CHẾ TẠO MÁY

BỘ MÔN CƠ SỞ THIẾT KẾ MÁY

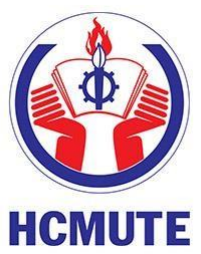
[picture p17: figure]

### ĐỒ ÁN THIẾT KẾ MÁY - MMH: PRMD310523

BẢNG TÓM TẮT KẾT QUẢ TÍNH TOÁN THIẾT KẾ

ĐỀ / P ÁN: 5/3

ĐIỂM HD: |
ĐIỂM PB: |

GVHD: Nguyễn Lê Đăng Hải

SVTH: Tống Bạch Trường Giang

NHÓM: 02

TP. Hồ Chí Minh, tháng 12 năm 2023

Trường ĐHSPKT TP.HCM Khoa: Cơ khí Chế tạo máy Bộ môn: Cơ sở Thiết kế máy | ĐỒ ÁN THIẾT KẾ MÁY, MMH: : PRMD310523 THIẾT KẾ HỆ THỐNG XÍCH TẢI Đề số: 05 -- Phương án: 03
SVTH: Tống Bạch Trường Giang GVHD: Nguyễn Lê Đăng Hải Ngày nhận đề: 28/08/2023 | MSSV: 21146220 Chữ ký: Ngày bảo vệ: 05/01/2024

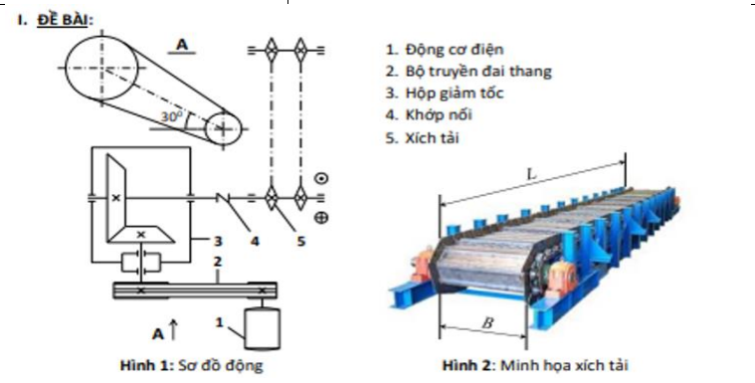
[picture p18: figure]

Điều kiện làm việc:
- Tải trọng không đổi, quay một chiều
- Thời gian làm việc 5 năm (300 ngày/năm, 2 ca/ngày, 6 giờ/ca) - Sai số tỉ số truyền hệ thống |Δu⁄u| ≤ 5% Số liệu cho trước:
STT | Tên gọi | Giá trị
1 | Bước xích tải p (mm) | 100
2 | Số răng đĩa xích dẫn Z (răng) | 9
3 | Chiều rộng xích tải B (m) | 0,8
4 | Chiều dài xích tải L (m) | 12
5 | Trọng lượng vật đúc G (kG) | 120
6 | Vận tốc xích tải V (m/s) | 0.75

PHẦN I: TÍNH TOÁN CÔNG SUẤT VÀ TỐC ĐỘ TRỤC CÔNG TÁC Bảng thông số trục công tác:
Thông số | Ký hiệu | Giá trị | Đơn vị
Số vòng quay trên trục | nlv | 50 | Vòng/phút
Công suất làm việc | Plv | 3.582 | kW

PHẦN II: CHỌN ĐỘNG CƠ PHÂN PHỐI TỈ SỐ TRUYỀN

### 1. Bảng thông số động cơ điện:

Mã động cơ ABB | M2QA160M8A
Công suất Pđc (kW) | 4
Tốc độ quay nđc (vòng/phút) | 715
Hệ số quá tải Tmax/TN | 1
Đường kính trục động cơ Dđc (mm) | 42

### 2. Bảng phân phối tỉ số truyền:

Trục Thông số | Động cơ | Trục I | Trục II | Trục công tác (trục làm việc)
Công suất P, kW | 3,96 | 3,81 | 3,65 | 3,62
Tỉ số truyền u | 4.54 | 3,15 | 1
Số vòng quay n, vg/ph | 715 | 157,5 | 50 | 50
Mômen xoắn T, N,mm | 52953 | 230774 | 698081 | 691100

PHẦN III: TÍNH TOÁN BỘ TRUYỀN NGOÀI Thông số đầu vào:
- Công suất trên trục 2: P2 = 3,96 kW
- Tốc độ quay của trục 2: n2 = 715 vòng/phút
- Tỉ số truyền: ux = 4,54
- Điều kiện làm việc: Tải trọng không đổi, quay 1 chiều,
- Thời gian làm việc: 5 năm (300 ngày/năm, 2 ca/ngày, 6 giờ/ca)
- Tóm tắt các bước tính toán:
1. Chọn loại đai : đai hình thang thường
2. Xác định các thông số của bộ truyền đai
- Công suất trên trục dẫn : Pct = 3,96 kW
- Số vòng quay trên trục dẫn: ndc = 715 (

vòng
phút)
- Tỉ số truyền bộ truyền đai: uđ = 4,54
- Đường kính bánh đai nhỏ: d1 =160 (mm)
- Đường kính bánh đai lớn: d2 =710 (mm)
- Tỉ số truyền thực tế : utt =

d2
d1.(1−ε)

= 4.53

- Kiểm tra sai lệch tỉ số truyền : ∆u =

ut – u
u

× 100% = 0.26% < 4%
- Xác định khoảng cách trục và chiều dài đai:

asơ bộ =

a
d

. d = 655,34
- Chiều dài đai tính toán :

l = 2a + π(d1+d2)
2

+

(d2−d1)^2
4a

= 2792,67 (mm)
=> Chọn chiều đai theo tiêu chuẩn : l = 2800 (mm)
- Tính lại chính xác khoảng cách trục :
a = 0,125.(2l-π(d1+d2)+√[2l − π(d1 + d2)] 2 − 8(d2 − d1)^2
= 659,36

- Tính góc ôm và kiểm tra điều kiện góc ôm : α1 = 180 − 57. (

d2−d1
a

) = 132,45 (độ)
- Xác định số đai Z :

Z = P1⋅kđ
[P0
| ]⋅Cα.Cu.Cl
.Cz

= 2,49 (đai)

=> Chọn z = 3 (đai)
- Chiều rộng bánh đai: B = (z-1)t+2e = 63
- Đường kính ngoài của bánh đai : da = d1 + 2h0 = 168,4
- Lực căng ban đầu F0 = 274,23 ( N)
- Lực tác dụng lên trục: = 2F0zsin(α1/2) = 1505,75 (N)

Các thông số của bộ truyền đai:

Loại đai: đai hình thang thường
Thông số | Kí hiệu | Gía trị | Đơn vị
Công suất trục dẫn | P | 3,58 | Kw
Tốc độ quay trục dẫn | n | 715 | v/p
Tỉ số truyền thực tế | ut | 4,53
Loại đai | Đai hình thang thường
Đường kính bánh đai nhỏ | d1 | 160 | mm
Đường kính bánh đai lớn | d2 | 710 | mm
Chiều dài đai | l | 2800 | mm
Khoảng cách trục | a | 659,36 | mm
Góc ôm | α1 | 132,45 | độ
Lực căng ban đầu | F0 | 274,23 | mm
Lực tác dụng lên trục | Fr | 1505,75 | N
Số đai | z | 4 | đai

PHẦN IV: TÍNH TOÁN BỘ TRUYỀN BÁNH RĂNG Thông số đầu vào:
- Công suất trên trục 1: P1 = 3,81 kW
- Tốc độ quay của trục 1: n1 =157,5 vòng/phút
- Moment xoắn trên trục 1: T1 =230774,88 Nmm
- Tỉ số truyền: ubr = 3.15

Tóm tắt các bước tính toán:

1. Chọn vật liệu : Thép C45
2. Xác định ứng suất cho phép

[σH1] = σHlim1×KHL1
SH

= 505,45 MPa

[σH2] = σHlim2×KHL2
SH

= 478,18 MPa

3. Tính bộ truyền bánh răng côn răng thẳng
3.1 Xác định đường kính chia ngoài hoặc chiều dài côn ngoài

Re = KR × √u

2 + 1 × √
(T1×KHβ)
(1−Kbe)×Kbe×u×[σH]

2 = 203,47 (mm)

- Đường kính chia ngoài :
de1 = 2 ×

Re
√1+u² = 123,13 (mm)
3.2 Xác định các thông số ăn khớp δ1 = arctg (

z1
z2

) = 17,55°

δ2 = 90° − 17,55° = 72,45°

4. Kiểm nghiệm răng về độ bền tiếp xúc:

σH = zM × zH × zξ√
2 × T1 × KH × √u
2 + 1
0,85 × b × u × dm1

2

= 474 ,82 MPa ≤ [σH]

5. Kiểm nghiệm răng về độ bền uốn: σF1 ≤ [σF1]max, σF2 ≤ [σF2]max

σF1 =

2×T1×KF×Yξ×Yβ×YF1
0,85×b×mtm×dm1

= 80,17 MPa

σF2 =

σF1×YF2

YF1

= 76,17 MPa

6. Kiểm nghiệm răng về quá tải

-Kiểm tra ứng suất tiếp cực đại cho phép σHmax = σH × √Kqt = 434,99 ≤ [σHmax] -Kiểm nghiệm ứng suất uốn cực đại cho phép:

σF1max = σF1 × Kqt = 80,17≤ [σF1max]

σF2max = σF2 × Kqt = 76,17≤ [σF2max]

7. Lực tác dụng lên bộ truyền bánh răng côn
- Lực vòng: Ft1 = 2 ×

T1

dm1

= 4253,91 = Ft2

- Lực hướng tâm: Fr1 = Fa2 = 1476,2 (N)
- Lực dọc trục: Fa1 = Fr2 = 466,96 (N) Kiểm tra sai số tỉ số truyền thực tế:
- Tỉ số truyền ban đầu: ubr = 3,15
- Tỉ số truyền thực tế: ubrtt = 3.16
- Kiểm tra sai số:
|ubrtt− ubr| | |3,16 – 3,15|
∆u = | × 100% = | × 100% = 0,35%
ucℎ | 3,15

Các thông số của bộ truyền bánh răng:
Thông số | Ký hiệu | Giá trị | Đơn vị
Tỉ số truyền | ubr | 3.15
Chiều dài côn ngoài | Re | 205,57 | mm
Mô đun vòng ngoài | mte | 4 | mm
Số răng của bánh răng dẫn | z1 | 31 | răng
Số răng của bánh răng bị dẫn | z2 | 98 | răng
Đường kính chia ngoài của bánh dẫn | de1 | 124 | mm
Đường kính chia ngoài của bánh bị dẫn | de2 | 392 | mm
Góc côn chia của bánh dẫn | δ1 | 17.55 | độ
Góc côn chia của bánh bị dẫn | δ2 | 72.45 | độ
Đường kính đỉnh răng ngoài của bánh dẫn | dae1 | 133.94 | mm
Đường kính đỉnh răng ngoài của bánh bị dẫn | dae2 | 393.68 | mm
Đường kính trung bình của bánh dẫn | dm1 | 108.5 | mm
Đường kính trung bình của bánh bị dẫn | dm2 | 343 | mm
Chiều cao răng ngoài | he | 8.8 | mm
Chiều cao đầu răng ngoài của bánh dẫn | hae1 | 5.212 | mm
Chiều cao đầu răng ngoài của bánh bị dẫn | hae2 | 2.788 | mm
Chiều cao chân răng ngoài của bánh dẫn | hfe1 | 3,588 | mm
Chiều cao chân răng ngoài của bánh bị dẫn | hfe2 | 6.012 | mm
Lực vòng | Ft1 = Ft2 | 4253 | N

Lực hướng tâm | Fr1, Fr2 | 1476; 466 | N
Lực dọc trục | Fa1, Fa2 | 466; 1476 | N

PHẦN V: TÍNH TOÁN THIẾT KẾ TRỤC Thông số đầu vào:
Momen xoắn trục I: T1 = 230774 Nmm
Moment xoắn trục II: T2 = 698081 Nmm

### 1. Khớp nối

Chọn kích thước cơ bản của nối trục đàn hồi và vòng đàn hồi

T = T2 = 698081.32 Nmm, k = 1.5

=> Tt = k*T = 1047.12 Nmm

Kích thước cơ bản của nối trục đàn hồi:

T, Nm | d, mm | D, mm | dm, mm | L, mm | l, mm | d1, mm | D0, mm | Z | nmax, N | B | B1 | L1, mm | D3, mm | l2, mm
2000 | 63 | 260 | 120 | 175 | 140 | 110 | 200 | 8 | 2300 | 8 | 70 | 48 | 48 | 48

Kích thước cơ bản của vòng đàn hồi:

T, Nm | dc, mm | dl, mm | D2, mm | l, mm | l1, mm | l2, mm | l3, mm | h, mm
2000 | 24 | M16 | 32 | 95 | 52 | 24 | 44 | 2
Kết quả tính toán

Lực hướng tâm của khớp nối tác dụng lên trục, Frnt = 1745.2 N

Điều kiện sức bền dập của vòng đàn hồi

+ [σ]d = 1.24 MPa

Điều kiện sức bền của chốt
+ [σ]u = 34 MPa
- Thoả điều kiện sức bền dập của vòng đàn hồi và sức bền của chốt

### 2. Sơ đồ phân tích lực trên bánh răng

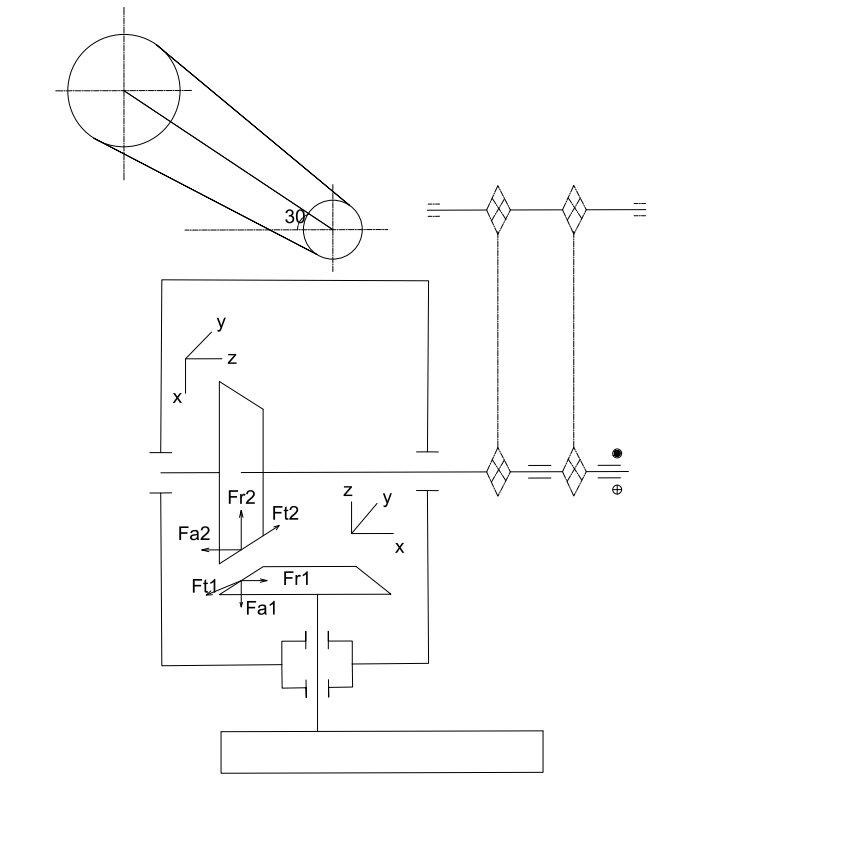
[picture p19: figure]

### 3. Biểu đồ nội lực các trục:

- Trục I:

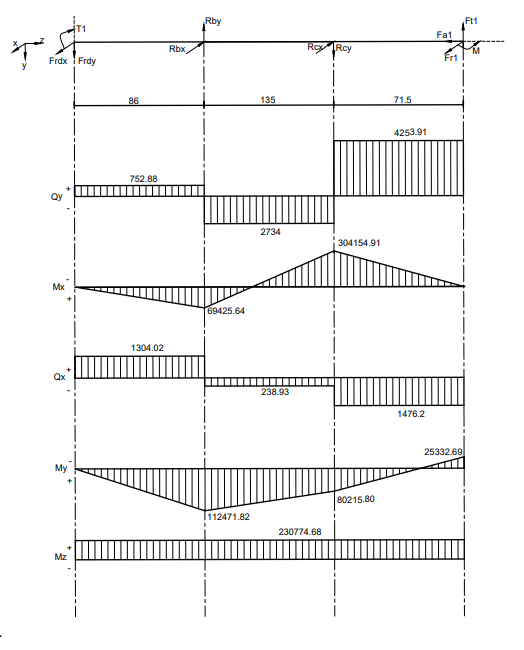
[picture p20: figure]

- Trục II:

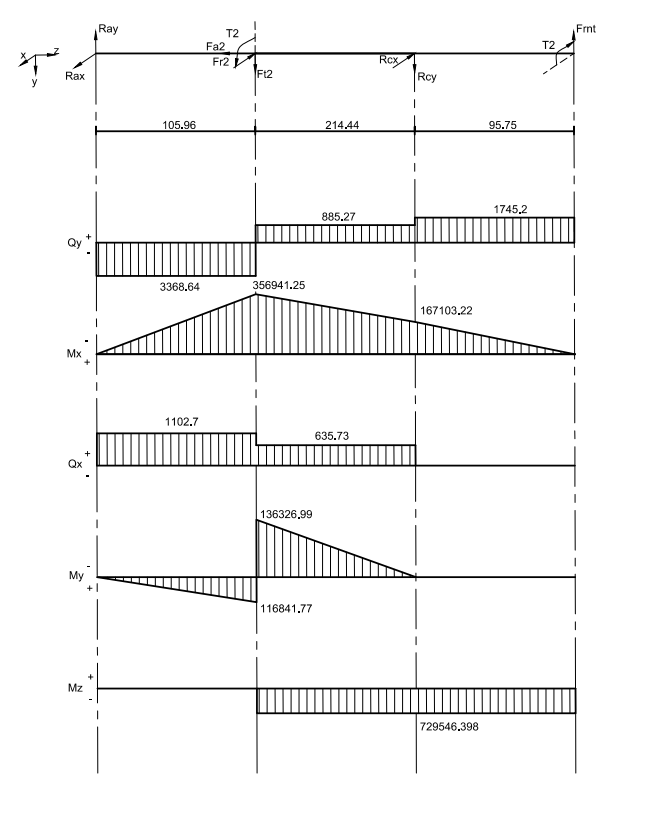
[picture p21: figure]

### 4. Thông số tính toán đường kính các trục

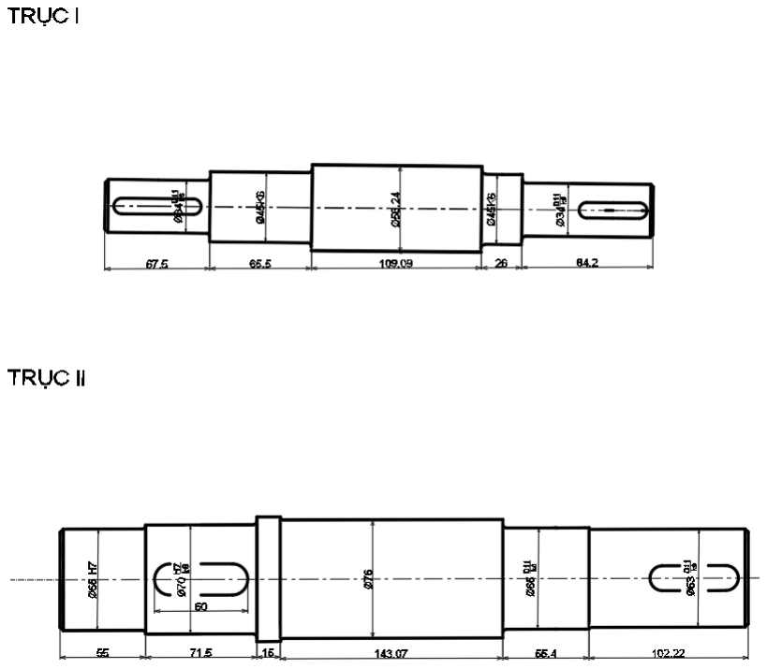
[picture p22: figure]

Chọn loại then: then bằng
Trục | Tiết diện | Chọn then | σd (MPa) | τc
| t1 (mm) | lt (mm) | (MPa) b x h
1 | 12 | 10x 8 | 5 | 57.38 | 78.87 | 23.66
| 13 | 10 x 8 | 5 | 49.73 | 91 | 27.3
2 | 22 | 20 x 12 | 7.5 | 60.78 | 76.22 | 17.15
| 23 | 18 x 11 | 7 | 70.13 | 82.57 | 17.78
Trục Vị trí | Trục 1 | Trục 2
0 | 34 | 65
1 | 45 | 70
2 | 45 | 65
3 | 34 | 63

### 5. Kết quả tính then

### 6. Ổ lăn

Thông số của ổ lăn:
- Trục I: ổ đũa côn, cỡ nhẹ
Ký hiệu | d (mm) | C, kN | C0 (kN) | Khối lượng(kg)
32008X/Q | 45 | 44.6 | 43 | 13.67
- Trục II: ổ đũa côn, cỡ nhẹ
Ký hiệu | d (mm) | C, kN | C0 (kN) | Khối lượng(kg)
JM511946 | 65 | 123 | 183 | 1.05

### 7. Dung sai Thống nhất ghi 3 kích

thước chính:
a. Trục I:
- Vòng trong ổ bi dùng k6 → ∅45k6 (∅45+0,002

+0.015)

- Vòng ngoài ổ bi dùng H7 → ∅80H7 (∅62+0

+0.03 )

- Lắp bánh răng, khớp nối dùng D11/k6 → ∅34D11/k6

- b. Trục II:
- Vòng trong ổ bi dùng k6 → ∅65k6 ∅65+0,002

+0.018)

- Vòng ngoài ổ bi dùng H7/d11 → ∅80H7/d11 (∅80+0,02

+0.03))

- Lắp bánh răng, đĩa xích dùng H7/k6 → ∅70H7/k6
c. Then
Trục I:
Vị trí | Trục I
12 | 10P9/h9
13 | 10P9/h9

Trục II:
Vị trí | Trục II
22 | 20P9/h9
23 | 18P9/h9

PHẦN VI: THIẾT KẾ VỎ HỘP

### 1. Bảng thông số vỏ hộp:

Vật liệu đúc vỏ hộp: gang xám GX 15-32
Tên gọi | Thông số | Giá trị | Đơn vị
Chiều dày | Thân hộp | δ | 9 | mm
| Nắp hộp | δ1 | 8 | mm
Đường kính | Bulông nền | d1 | 16 | mm
| Bulông cạnh ổ | d2 | 12 | mm
| Bulông ghép bích nắp và thân | d3 | 10 | mm
| Vít ghép nắp ổ | d4 | 8 | mm
| Vít ghép nắp cửa thăm | d5 | 6 | mm
Mặt bích ghép nắp và thân | Chiều dày bích thân hộp | S3 | 16 | mm
| Chiều dày bích nắp hộp | S4 | 16 | mm
| Bề rộng bích nắp và thân | K3 | 37 | mm
Kích thước gối trục | Đường kính ngoài và tâm lỗ vít | D12 | 75 | mm
| | D13 | 90 | mm
| | D22 | 100 | mm
| | D23 | 125 | mm
| Bề rộng mặt ghép bulông cạnh ổ | K2 | 45 | mm
| Tâm lỗ bulông cạnh ổ | C1 | 45 | mm
| | C2 | 63 | mm
| Chiều dày | e | 8 | mm

Gân tăng cứng | Chiều cao | h | < 58 | mm
Độ dốc | | 2 o
Mặt đế hộp | Chiều dày (không có phần lồi) | S1 | 24 | mm
| Bề rộng mặt đế hộp | K1 | 48 | mm
Khe hở giữa các chi tiết | Giữa bánh răng và thành trong hộp | ∆ | 10 | mm
| Giữa bánh răng lớn với đáy hộp | ∆1 | 24 | mm
| Giữa mặt bên các bánh răng với nhau | ∆ | 10 | mm
Số lượng bulông nền | | Z | 4

### 2. Một số chi tiết phụ - Bulông vòng:

Chức năng: để nâng và vận chuyển hộp giảm tốc (khi gia công, khi lắp ghép,…) nên nắp và thân thường lắp bulông vòng hoặc vòng móc. Với Re = 129, khối lượng hộp giảm tốc bánh răng côn Q = 60 kg

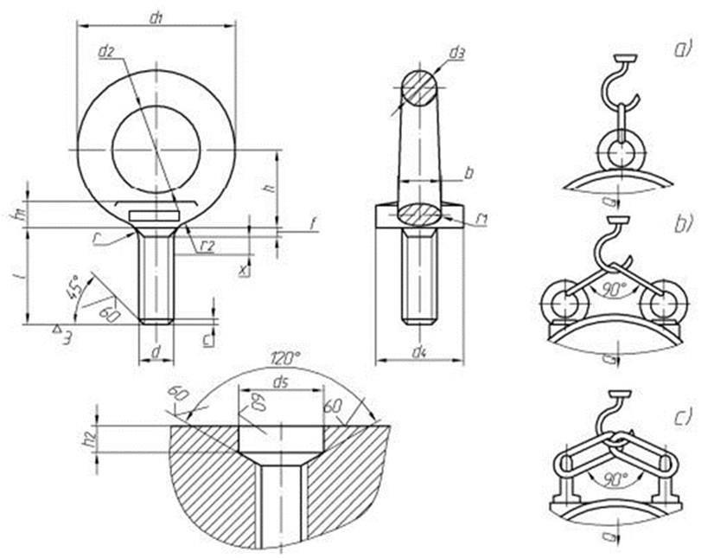
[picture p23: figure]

Ren d | d1 | d2 | d3 | d4 | d5 | h | h1 | h2 | f | b | c | x | r | r1 | r2 | l
M8 | 36 | 20 | 8 | 20 | 13 | 18 | 6 | 5 | 2 | 10 | 1.2 | 2.5 | - | 4 | 4 | 18
- Chốt định vị:
Chức năng: khi xiết bulông không làm biến dạng vòng ngoài của ổ, do đó loại trừ được một trong nguyên nhân làm ổ chóng bị hỏng. Chọn chốt định vị: chốt định vị hình côn

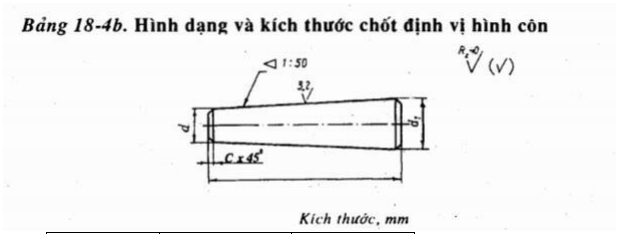
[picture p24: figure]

d | c | l
5 | 0.8 | 16…90
- Nắp quan sát:
Chức năng: để quan sát các tiết máy trong hộp khi lắp ghép và để đổ dầu vào hộp, trên đỉnh hộp có làm cửa thăm.


- Nút thông hơi:
Chức năng: khi làm việc nhiệt độ trong hộp tăng lên. Để giảm áp suất và điều hòa không khí bên trong và bên ngoài hộp, người ta dùng nút thông hơi.
A | B | A1 | B1 | C | C1 | K | R | Vít | Số lượng
100 | 75 | 150 | 100 | 125 | - | 87 | 18 | M8x22 | 4


A | B | C | D | E | G | H | I | K | L | M | N | O | P | Q | R | S
M27X 2 | 1 5 | 3 0 | 1 5 | 4 5 | 3 6 | 3 2 | 6 | 4 | 1 0 | 8 | 2 2 | 6 | 3 2 | 1 8 | 3 6 | 3 2
- Nút tháo dầu:
Chức năng: sau một thời gian làm việc, dầu bôi trơn chứa trong hộp bị bẩn (do bụi bặm và do hạt mài), hoặc bị biến chất, do đó cần phải thay dầu mới. Để tháo dầu cũ, ở đáy hộp có lỗ thảo dầu. Lúc làm việc lỗ được bịt kín bằng nút tháo dầu.


d | b | m | f | L | c | q | D | S | D0
M20x2 | 15 | 9 | 3 | 23 | 2 | 13.8 | 26 | 17 | 19.6

- Que thăm dầu: Chức năng: khi vận tốc bánh răng được ngâm trong dầu. Chiều cao mức dầu trong hộp được kiểm tra qua thiết bị chỉ dầu là que thăm dầu.


### TÀI LIỆU THAM KHẢO

PGS. TS. Trịnh Chất – TS. Lê Văn Uyển (1999), Tính toán thiết kế hệ dẫn động cơ khí tập 1, Nxb. Giáo dục Việt Nam, Tp. Hồ Chí Minh. PGS. TS. Trịnh Chất – TS. Lê Văn Uyển (1999), Tính toán thiết kế hệ dẫn động cơ khí tập 2, Nxb. Giáo dục Việt Nam, Tp. Hồ Chí Minh.

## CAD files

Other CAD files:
Auto_CAD.dwg
